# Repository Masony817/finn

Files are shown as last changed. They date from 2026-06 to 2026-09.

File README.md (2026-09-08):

# FINN

**FINN** is a self-balancing, two-wheeled humanoid style robot. The current state is an open hardware/software
platform for balance control, system identification, and sim-to-real work. This
repo holds everything for the robot: firmware, a system-ID pipeline that
turns bench measurements into a physically-grounded MuJoCo model, and a MuJoCo
sim with a first LQR balance controller.

Status: early and under active solo development. Interfaces move fast and the
controllers are sim-validated, not yet hardware-tuned (see
[Status & limitations](#status--limitations)). If you're building a similar
two-wheeler or reusing the control/sysid tooling, it should be a useful
starting point - hopefully. Issues and questions are more than welcome.

Licensed under [Apache 2.0](LICENSE).

## Repository layout - under development and active changes

```
firmware/finn-mcu/   Teensy 4.1 firmware (PlatformIO) + MJBots Moteus motor control,
                     including system-ID, safety-gated LQR, and capture tools
sim/
  model/finn/        Hand-authored MuJoCo model, meshes (STL), and scene
  config/            Canonical measurements + postprocess config (source of truth)
  generated/         Generated seed models (only the reference bundle is committed)
src/finn/            Shared control, simulation, model, reporting, telemetry
tools/               Host-side CLIs: build the seed model, run the LQR sim,
                     postprocess sysid, environment check
tests/               pytest suite for the host tools
config/              Frame/sign contracts, Scopik profiles, and local motor config
```

## Quick start (host / sim)

Requires Python 3.11 and [uv](https://docs.astral.sh/uv/). Nothing else is
needed for the sim — MuJoCo and SciPy install as self-contained wheels.

```bash
uv sync --locked --extra dev            # create .venv from the locked deps
uv run python tools/check_env.py        # verify the toolchain imports
uv run python tools/run_lqr_sim.py      # run the LQR balance sim
```

To watch the closed-loop controller balance Finn in real time on macOS, run
the same simulation through MuJoCo's `mjpython` launcher. The isolated
Homebrew-Python environment is intentional: `mjpython` requires a framework
Python, while uv's standalone Python does not expose the shared library it
needs.

```bash
uv run --isolated --python /opt/homebrew/bin/python3 \
  mjpython tools/run_lqr_sim.py --viewer --duration-s 30
```

On Linux, use `uv run python tools/run_lqr_sim.py --viewer --duration-s 30`.
Closing the viewer stops the rollout and still writes the partial validation
bundle to `logs/lqr_sim/<ts>/`.

Motor calibration utilities are optional because their Qt GUI dependencies are
large. Install them only on machines that talk to the hardware:

```bash
uv sync --extra dev --extra hardware
```

`run_lqr_sim.py` loads the committed seed model at
`sim/generated/seeded/latest/finn.seeded.sim.xml`, linearizes the balance
dynamics, designs a discrete LQR gain, and runs a closed-loop MuJoCo rollout.
It writes a timeseries CSV, a JSON report, and a plot to `logs/lqr_sim/<ts>/`.
By default it derives the stationary balance trim from the model's axle-to-COM
offset and uses a slower position outer loop to prevent accumulated wheel creep.
Override the trim with `--target-pitch-rad`, or disable position hold with
`--position-hold-kp-s 0`, when testing the inner balance loop in isolation.
See `--help` for tuning knobs (Q/R weights, initial pitch, duration).

## Sim-to-real gap profiling

[`packages/scopik`](packages/scopik) replays a recorded Finn run through the
seeded MuJoCo model, compares signals phase by phase, and writes deterministic
bias/RMS/gain/lag diagnostics alongside a Rerun dashboard:

```bash
uv run scopik gap --profile config/viz/finn.yaml \
  --run logs/finn-mcu/sysid/batch_2_pass/<timestamp>
```

Use the repo's `finn-gap-review` agent skill after a run when you want a
physics-grounded brief that connects those measurements to the next model
parameter or validation check.

## Real-robot LQR bring-up

The repo now has a deliberately gated Teensy controller and capture path for
the first unsupported-floor balance trials. Start with the motor-disabled frame
and sign check; the firmware will not arm until those physical observations are
recorded in `config/finn_conventions.yaml` and a passing sim run regenerates the
controller header.

See [Real-robot LQR bring-up](docs/real_lqr_bringup.md) for the exact commands,
two-person no-stand procedure, safety limits, and Scopik feedback loop.

## From robot to model: the system-ID pipeline

The MuJoCo model is not guessed — its wheel friction, damping, torque limits,
and inertias come from measurements. The flow is:

1. **Bench + on-robot sysid.** Firmware sketches under
   `firmware/finn-mcu/sysid/` excite the wheels/IMU; capture tools log the
   telemetry.
2. **Postprocess** each batch into identified parameters
   (`tools/postprocess_mujoco.py`, `firmware/finn-mcu/tools/postprocess_*`).
3. **Build the seed model** from the latest clean runs:
   ```bash
   uv run python tools/build_seeded_mujoco_model.py --auto-select-latest 3
   ```
   This aggregates the runs, writes `seeded_measurements.yaml`, and emits the
   MuJoCo XML the sim consumes.

**Raw sysid telemetry is intentionally not committed** — it's large and
robot-specific (see `.gitignore`). The committed
`sim/generated/seeded/latest/` bundle is a working reference model plus its
provenance (`selected_runs.json`, `aggregation_report.md`). If you're building
your own robot, capture your own sysid batches and regenerate the model against
them; if you just want to run the sim, the committed bundle is enough.

## Firmware

The Teensy 4.1 firmware lives in `firmware/finn-mcu/` and builds with
PlatformIO (`pio run`). It talks to moteus motor controllers over CAN-FD. CI
compiles every `[env:*]` in `platformio.ini` and runs cppcheck, so the MCU code
is build-verified on every push.

## Status & limitations

- The LQR gain and trim are **sim validated, not hardware tuned**. The real
  controller starts behind physical sign checks, a host heartbeat, a three-second
  trial limit, and conservative fault limits. The seeded `±1.0 N·m` torque
  envelope recovers about 11 degrees of lean in sim and caps chassis acceleration
  near 3 m/s²; hub-motor capability is much higher, but the first trials
  intentionally do not use it.
- Contact parameters (friction, solref, solimp) are provisional defaults, not
  identified. World-pose / slip accuracy and closed-loop sim-to-real transfer
  are explicitly **not** validated yet.

## Development

```bash
uv run ruff check .          # lint
uv run ruff format .         # format
uv run pytest -q             # host tests; requires a C++ compiler
```

CI runs lint, format-check, tests, and the firmware build on every push to
`main`/`dev` and on PRs.

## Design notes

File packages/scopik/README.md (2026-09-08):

# scopik

**A sim-to-real gap profiler built on [Rerun](https://rerun.io).**

Every robotics project with a simulator eventually asks the same three questions:
*how wrong is my model, where in the run does it diverge, and is it getting better as I
tune it?* Answering them usually means a pile of private matplotlib scripts. scopik is
that pile, done once, properly: bring a MuJoCo model, a robot log, and a ~40-line YAML
profile - get a scrubbable dashboard and a tracked gap history.

```sh
scopik gap --profile config/viz/finn.yaml --run logs/finn-mcu/sysid/batch_2_pass/<ts>
```

```
sim-to-real gap  (5 signals, model: .../finn.seeded.sim.xml)
  signal           unit         rmse        mae  max |err|       n
  ----------------------------------------------------------------
  left_vel         rev/s      0.4387     0.1365      2.979   34075
  right_vel        rev/s      0.4114     0.1241      2.831   34075
  pitch_rate       rad/s     0.01553   0.004634     0.2011   34075
  yaw_rate         rad/s     0.09119    0.03268     0.8195   34075
  forward_accel    m/s²       0.1637    0.07488      1.846   34075
```

## What it does

`scopik gap` loads a recorded run, replays its recorded actuator commands **open-loop**
through the MuJoCo model (each command held for the real inter-sample interval), samples
the model's sensors on the real run's own timestamps, and logs everything to Rerun:

- **Overlay charts** - real and sim in the same plot per compared signal.
- **Residual + rolling RMSE** - model error *localized in time*. A residual spike at
  breakaway points at stiction; error during a PRBS segment points at inertia or
  damping; drift during coastdown points at friction.
- **Events and phases** - lifecycle events and phase-column changes as timeline
  annotations, so a 10-minute sysid run is navigable by segment.
- **Summary** - per-signal RMSE / MAE / max-error table, in the viewer and as
  `scopik_gap.json` next to the run.
- **Deterministic diagnosis** - per phase and signal, compute bias, RMS, gain,
  correlation, and lag. Unsupported gain/lag estimates are written as `null`
  instead of being inferred from quiet sensor noise; findings aggregate the
  strongest patterns without requiring an LLM.
- **Gap history** - each run appends one JSON line (timestamp, model hash, per-signal
  metrics) to `<profile>_gap_history.jsonl`. Tune the model, rerun, watch the numbers
  move. This is the regression-tracking habit that makes the gap actually close.

## Reading the dashboard

The viewer opens with three kinds of tabs:

| Tab | Question it answers |
|---|---|
| **Overview** | How wrong is everything at a glance? All real-vs-sim overlays, plus the summary table and event log. |
| **One tab per signal** | Where does this signal diverge? Big overlay on top, residual + rolling RMSE below. Scrub to the spikes. |
| **Telemetry** | What was the robot actually doing? Raw signal groups (attitude, wheels, commands, health, ...). |

The timeline panel at the bottom scrubs every panel in sync. Double-click a plot to
expand it; drag on the timeline to zoom a segment.

## Physical honesty

Two problems bite every naive sim-vs-real comparison, and scopik has explicit,
opt-in answers for both:

**Gravity in accelerometers.** A MuJoCo accelerometer reports *specific force*
(gravity included) in the sensor's site frame; real IMUs typically report
gravity-removed linear acceleration. `gravity_compensated: true` on a replay sample
subtracts the gravity-reaction term using the site's live orientation each frame -
correct at any attitude, not just upright. On finn this took the forward-acceleration
"gap" from a meaningless 9.7 m/s² (≈ g) to a real 0.16 m/s².

**Externally supported runs.** If the real robot was on a gantry or stand during the
recording, the bare model has no such support - an unbalanced model simply falls over
during open-loop replay, and every comparison is polluted by fall dynamics.
`hold_upright: <free_joint>` models an ideally stiff support: roll and pitch are
projected out every physics step; yaw and translation stay free. The summary panel
states when a hold is active.

And the standing caveat: this is an **onboard-signal, open-loop** comparison.
Rate and velocity signals are the honest comparison set; absolute pose is not
validated by replay.

Replay refuses non-finite commands and non-increasing timestamps rather than
inventing inputs. Intervals are rounded to physics steps and gaps above 0.1 s
are capped; the dashboard and JSON report expose clipped intervals and cumulative
time error. Do not interpret lag as physical latency when these adjustments
are significant.

## The profile

One YAML file adapts scopik to a robot. Paths are relative to the profile file.

```yaml
name: myrobot
model: ../sim/myrobot.xml            # MJCF the replay runs against

source:                              # how to parse the log
  type: prefixed_csv                 # or csv
  file: telemetry.csv
  line_prefix: "data,"               # rows start with this tag
  header_marker: "data,t_us,"        # the first matching line is the CSV header

time: {column: t_us, transform: us_to_s}

signals:                             # column -> chart, with units and transforms
  pitch_rad:      {unit: rad,   group: attitude}
  left_vel_rev_s: {unit: rev/s, group: wheels}
  motor_temp_c:   {unit: "°C",  group: health}

events:                              # optional: timeline annotations
  file: events.log
  prefix: "event,"
  time_index: 1                      # csv field holding the timestamp
  time_transform: us_to_s
  phase_column: phase                # text column whose changes get annotated

replay:                              # optional: enables the sim side + metrics
  actuators: {motor_left: left_cmd_nm}   # model actuator <- command column
  hold_upright: root_freejoint           # optional: ideal external support
  sample:                                # model sensors -> sim signals
    left_vel_rev_s: {sensor: wheel_left_vel, transform: rad_to_rev, unit: rev/s}
    forward_accel:  {sensor: imu_accel, index: 2, gravity_compensated: true}

compare:                             # real signal vs sim signal, by name
  - {name: left_vel, real: left_vel_rev_s, sim: left_vel_rev_s, unit: rev/s}
```

Transforms: `rev_to_rad`, `rad_to_rev`, `deg_to_rad`, `us_to_s`, `ms_to_s`, `negate`,
`{scale: x, offset: y}`, or a list to chain them. The full worked example is finn's
[`config/viz/finn.yaml`](../../config/viz/finn.yaml).

## CLI

```
scopik gap --profile P.yaml --run RUN_DIR      # open the native viewer (default)
    --save out.rrd        write a shareable recording instead
    --serve               host for a connecting viewer
    --no-replay           charts + events only, no sim / metrics
    --model M.xml         override the profile's model
    --window-s 2.0        rolling RMSE window (default 1.0)
    --out gap.json        metrics JSON path (default: RUN_DIR/scopik_gap.json)
    --history H.jsonl     gap history path; --no-history to skip
```

Recordings (`.rrd`) open with `rerun file.rrd` or the web viewer - that's the
share-a-run story: send the file, the recipient scrubs the same dashboard.

For a Finn-specific physical interpretation, invoke `finn-gap-review` in Codex
or `/finn-gap-review` in Claude Code. Both entrypoints use the same checked-in
workflow and treat Scopik's numeric output as evidence rather than asking an LLM
to re-estimate time-series features.

## Scope

Scopik's main job is recorded open-loop sim-to-real comparison. Finn's capture
tools write complete logs first, then invoke `scopik gap` after the motors are
stopped. Generic plugins and 3D reconstruction stay out until a real robot
workflow requires them.

Live streaming was in that same holding pattern until teleop needed it. Driving a
balancing robot by hand is a workflow a post-hoc gap report cannot serve, so
`scopik.live` exists now:

```python
from scopik.live import LiveSession

session = LiveSession.from_columns({"attitude": ("pitch_rad", "yaw_rate_rad_s")})
session.spawn()                      # or .save(path) for CI
session.log_row(time_s, row)         # once per control tick
session.close()
```

It is deliberately much smaller than the gap pipeline: no profile, no model, no
comparison, just named scalars on a shared timeline. A missing column is skipped
rather than raised, because a live sink must never be able to interrupt the
control loop feeding it. `tools/drive_lqr_sim.py` is the reference caller.

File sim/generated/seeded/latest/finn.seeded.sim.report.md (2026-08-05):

# Finn MuJoCo Postprocess Report

- status: `ok`
- strict: `False`

## Inputs
- robot: `sim/model/finn/finn_robot.xml`
- scene: `sim/model/finn/scene.xml`
- config: `sim/config/mujoco_postprocess.yaml`
- measurements: `sim/generated/seeded/latest/seeded_measurements.yaml`
- robot_sha256: `5f6efd330880e4f90dd55f0cedcf454640507549607517dc8a8347013dfbdcfa`
- scene_sha256: `89402558d8c14cec25d80d707238bdd4679cb2d03deae2740c4df397a81d4c57`
- config_sha256: `9bee25e0d508273d1e2ba68235594842f72ff06dbf8bd16e912f3bdfbdfc83ce`
- measurements_sha256: `eed45ac84e7b11befb13326a1758e1865f2ac3917a9644c5193862d73fb6491b`
- onshape_url: `https://cad.onshape.com/documents/ed1c90944582329b3a0c4b53/w/ef6c6e50f2f631eadb017a5a/e/35effa0e1acd53deffeb4bb9`

## Inspection
- root_body: `base_2`
- wheels: `{'left': {'body': 'left_wheel', 'joint': 'left_wheel', 'center_site': 'left_wheel_center'}, 'right': {'body': 'right_wheel', 'joint': 'right_wheel', 'center_site': 'right_wheel_center'}}`
- visual_mesh_geoms: `23`
- collision_mesh_geoms: `23`
- generated_position_actuators: `['left_wheel', 'right_wheel']`

## Missing Measurements
- none

## Measurements Used
- wheels.left.radius_m: `0.081` m (source: `measured`)
- wheels.left.width_m: `0.053` m (source: `measured`)
- wheels.left.torque_limit_nm: `1.0` N*m (source: `reviewed`)
- wheels.left.gear_ratio: `1.0` ratio (source: `measured`)
- wheels.left.command_sign: `-1` sign (source: `moteus`)
- wheels.left.damping: `0.00410667` N*m*s/rad (source: `moteus`)
- wheels.left.armature: `0.0` kg*m^2 (source: `moteus`)
- wheels.left.frictionloss: `0.115429` N*m (source: `moteus`)
- wheels.left.mass_kg: `2.1` kg (source: `measured`)
- wheels.right.radius_m: `0.081` m (source: `measured`)
- wheels.right.width_m: `0.053` m (source: `measured`)
- wheels.right.torque_limit_nm: `1.0` N*m (source: `reviewed`)
- wheels.right.gear_ratio: `1.0` ratio (source: `measured`)
- wheels.right.command_sign: `1` sign (source: `moteus`)
- wheels.right.damping: `0.00441399` N*m*s/rad (source: `moteus`)
- wheels.right.armature: `0.0` kg*m^2 (source: `moteus`)
- wheels.right.frictionloss: `0.126772` N*m (source: `moteus`)
- wheels.right.mass_kg: `2.1` kg (source: `measured`)
- contact.tire.friction: `[1.0, 0.02, 0.002]` slide torsional rolling (source: `estimated`)
- contact.tire.solref: `[0.02, 1.0]` timeconst dampratio (source: `estimated`)
- contact.tire.solimp: `[0.9, 0.95, 0.001, 0.5, 2.0]` dmin dmax width midpoint power (source: `estimated`)

## Changes
- root: `{'renamed_from': 'base_2', 'renamed_to': 'base_link', 'freejoint_added': True, 'freejoint_name': 'root_freejoint', 'initial_clearance_m': 0.003, 'lift_applied_m': 0.044000000000000004, 'wheel_world': {'left': {'center_z_before_lift_m': 0.04, 'bottom_z_before_lift_m': -0.041}, 'right': {'center_z_before_lift_m': 0.04, 'bottom_z_before_lift_m': -0.041}}}`
- removed_collision_geoms: `[{'name': None, 'mesh': 'motor_hub', 'material': 'motor_hub_material', 'region': 'wheel'}, {'name': None, 'mesh': 'motor_tire', 'material': 'motor_tire_material', 'region': 'wheel'}, {'name': None, 'mesh': 'motor_hub', 'material': 'motor_hub_material', 'region': 'wheel'}, {'name': None, 'mesh': 'motor_tire', 'material': 'motor_tire_material', 'region': 'wheel'}]`
- removed_actuators: `[{'tag': 'position', 'name': 'left_wheel', 'joint': 'left_wheel'}, {'tag': 'position', 'name': 'right_wheel', 'joint': 'right_wheel'}]`
- updated_joints: `[{'wheel': 'left', 'joint': 'left_wheel', 'damping': 0.00410667, 'armature': 0.0, 'frictionloss': 0.115429}, {'wheel': 'right', 'joint': 'right_wheel', 'damping': 0.00441399, 'armature': 0.0, 'frictionloss': 0.126772}]`
- updated_inertials: `[{'wheel': 'left', 'body': 'left_wheel', 'mass_kg': 2.1}, {'wheel': 'right', 'body': 'right_wheel', 'mass_kg': 2.1}]`
- added_actuators: `[{'name': 'motor_left_wheel', 'joint': 'left_wheel', 'gear': -1.0, 'ctrlrange': [-1.0, 1.0]}, {'name': 'motor_right_wheel', 'joint': 'right_wheel', 'gear': 1.0, 'ctrlrange': [-1.0, 1.0]}]`
- added_collision_geoms: `[{'name': 'left_tire_collision', 'body': 'left_wheel', 'type': 'cylinder', 'condim': 6, 'radius_m': 0.081, 'half_width_m': 0.0265}, {'name': 'right_tire_collision', 'body': 'right_wheel', 'type': 'cylinder', 'condim': 6, 'radius_m': 0.081, 'half_width_m': 0.0265}]`
- added_sensors: `[{'tag': 'gyro', 'name': 'imu_gyro', 'target': 'imu'}, {'tag': 'accelerometer', 'name': 'imu_accelerometer', 'target': 'imu'}, {'tag': 'framequat', 'name': 'imu_quat', 'target': None}, {'tag': 'framepos', 'name': 'base_pos', 'target': None}, {'tag': 'framequat', 'name': 'base_quat', 'target': None}, {'tag': 'jointpos', 'name': 'wheel_left_pos', 'target': 'left_wheel'}, {'tag': 'jointvel', 'name': 'wheel_left_vel', 'target': 'left_wheel'}, {'tag': 'jointpos', 'name': 'wheel_right_pos', 'target': 'right_wheel'}, {'tag': 'jointvel', 'name': 'wheel_right_vel', 'target': 'right_wheel'}]`
- scene: `{'compiler_meshdir': '../../../model/finn/assets', 'visual_merged': True, 'assets_merged': 3, 'worldbody_children_merged': 2}`

## Validation
- sensor_model: `ideal; no noise/filter settings were applied`
- mujoco: `{'status': 'ok', 'nbody': 4, 'njnt': 3, 'nu': 2, 'nsensor': 9, 'zero_control_steps': 25}`

## Errors
- none

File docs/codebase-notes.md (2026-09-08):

# Codebase notes

Cross-cutting facts that are easy to get wrong and belong to no single file.
Conventions and rules live in `CLAUDE.md`; this is the reference behind them.

## Signal frames

`config/finn_conventions.yaml` is the contract. Robot +x is forward, +y left,
+z up. The BNO085 is mounted so its own axes do not line up with the robot's:

| Robot quantity | IMU sensor axis | Sign |
|---|---|---|
| pitch, pitch rate | X | +1 |
| yaw, yaw rate | Y | +1 |
| forward acceleration | Z | -1, sensor +Z points aft |

Both physical wheel encoders read positive for robot-forward motion. The
generated MuJoCo model mirrors its left joint, so the simulated left wheel reads
negative for the same motion and Scopik negates only that sensor. These are
separate from the model's own joint-to-world mapping, which is not the same
pairing; `config/finn_conventions.yaml` explains why and holds both.

## MuJoCo

**Accelerometers report specific force**, gravity included, in the sensor site
frame. The firmware publishes BNO085 linear acceleration with gravity already
removed. Comparing them raw shows a ~9.7 m/s^2 gap that is just g, which is why
replay samples take `gravity_compensated: true` and subtract the gravity-reaction
term from the site's live orientation each frame.

**`framequat` objtype matters.** `objtype="body"` reports the body's inertial
(principal-axis) frame, not its body frame; `objtype="xbody"` reports the body
frame. They differ whenever the inertia tensor is not axis-aligned, and the
difference is silent. The seeded model reads attitude off `objtype="site"`
sensors, which sidesteps this.

**A bare model falls over.** Finn is an inverted pendulum, so open-loop replay of
a gantry-supported recording tips within about two seconds and pollutes every
signal with fall dynamics. `hold_upright: <freejoint>` projects roll and pitch
out each step to model an ideally stiff support, leaving yaw and translation
free. Use it only for runs that really were externally supported.

## Control layering

The balance loop is always on. Everything that steers Finn sits above it and can
only move a bounded reference, never a torque. Keyboard teleop is the first tenant of
that layer; an HRI or navigation policy is meant to be the next one, and the
boundary accepts bounded references. Current callbacks run synchronously and
must return immediately; a slow producer must publish through a separate worker
before it can use this interface.

```
L3  command sources   keyboard teleop | scripted profile | (later) a policy
      |               returns DriveCommand(forward_vel_m_s, yaw_rate_rad_s)
L2  command arbiter   holds, clamps, slew-limits, ramps stale commands to zero
      |               output is a reference, never a torque
L1  balance + yaw     runs every tick whether or not a command ever arrives
      |               balance torque allocated first, yaw gets the headroom
L0  safety / arming   stops everything above it; nothing above relaxes it
```

Five invariants, each with a test named for it in
`tests/test_run_lqr_sim_smoke.py` and `tests/test_drive_lqr_sim.py`:

1. **L1 never depends on L3 existing.** With no command source, the rollout is
   identical to the station-keeper, which is what lets the generated firmware
   header keep being exported from the plain balance path.
2. **L3 cannot reach torque.** A command source takes `time_s` and returns a
   `DriveCommand`. It gets no `MjData`, no handles, no gains. This is why the
   `on_tick` hook `make_balance_demo.py` uses for shoves is *not* the teleop seam:
   `on_tick` hands out `MjData`, and it fires after the torque is already computed.
3. **L2 fails closed and fails soft.** A source that raises, returns non-finite or
   wrong-typed values, or goes silent is held briefly and then *ramped* to zero.
   Ramped, not stepped: a step is itself a disturbance the balance loop must reject.
4. **L2 holds intermittent commands.** L1 runs at 100 Hz and continues ramping
   toward the last requested target between samples, until timeout. Callbacks
   must return immediately; this interface does not isolate blocking producers.
5. **Balance has torque priority.** `allocate_wheel_torques` clamps the balance
   torque first and gives yaw only the leftover headroom, so a saturated balance
   loop steers not at all rather than losing authority to a turn request.

Key release, a dropped link, and a stopped policy are the same event to L2, which
is why the teleop release path is also the policy-failure path.

## Viewer keys

Use arrow keys to drive and space to stop. MuJoCo binds every letter to a
rendering shortcut, so Finn does not bind WASD or maintain viewer-flag workarounds.

## Hold to drive

`key_callback` is `Callable[[int], None]`: a keycode and nothing else. No release
events, and no way to separate a press from an auto-repeat. Everything a callback
can manage on its own is therefore a latch - stamp each press, treat the key as
held while the stamp is fresh - and that is a poor joystick. It needs auto-repeat
to arrive, it stutters when the repeat delay outlasts the window, and it keeps
driving for a whole window after release. A 30 s hand-driven session produced no
command plateau longer than a single tick.

GLFW knows the true state of every key and MuJoCo already depends on it. The one
missing piece is the window handle, which the viewer does not expose. It can be
taken instead: `key_callback` runs on the thread holding the GL context, so the
first keypress captures it with `glfw.get_current_context()`. After that
`held()` reads real state, and holding a key holds the command.

GLFW calls fall back to the latch on Python exceptions; this is a best-effort
simulator UI adapter, not a hardware command transport or a thread-safety
guarantee. `report.json` records `key_state_polling`.

## Judging a driven rollout

`run_lqr_sim.py`'s pass gate assumes station keeping: hold a spot, end upright at
trim. Every one of those criteria is wrong for a rollout that was told to drive,
and each was found by a driven run failing for a reason that was actually correct
behaviour.

- **Position hold** becomes command tracking, since a driving robot is not trying
  to hold a spot.
- **Ending upright** allows the lean a still-accelerating command requires.
  Holding forward acceleration `a` costs a steady lean of `atan(a/g)`, so a run
  that stops mid-ramp is upright exactly when it sits inside that plus the
  settling slack.
- **Tracking error** is scored only on samples whose command has been steady for
  `COMMAND_SETTLE_S`, so the slew ramps are not counted as failures, and only on
  *nonzero* commands, and as a p95 rather than a max because a hard spin makes the
  tires stick and slip.

That last filter matters more than it looks. Grading zero commands means grading a
standing robot against a stop, which it always wins. A 30 s hand-driven session
scored 1186 such samples, reported `yaw_tracking_p95 = 0.0009` while yaw had been
commanded to plus and minus 1.0 rad/s, and passed - because a human never holds a
key still for 1.5 s, so not one moving sample was ever graded. The metrics now
carry `*_tracking_assessed` and `*_tracking_samples`, and an unassessed gate says
so instead of printing a reassuring number.

Interactive sessions routinely come back unassessed. That is the honest answer:
the checks that need no steady command - did not fall, ended upright, stayed
inside the torque envelope, did not saturate - still apply.

## Steering signs

Two traps, both recorded in `config/finn_conventions.yaml`.

**The generated model's wheel names are backwards.** `motor_left_wheel` drives the
wheel at world y = -0.009 and `motor_right_wheel` the one at y = +0.508, while
robot +y is left. The names come from the CAD export. Balance never noticed,
because both wheels get the same torque; steering is the first thing that needs
them to differ, and a sign read off the names turns left into right.
`yaw.sim_left_actuator_yaw_sign` carries it, and
`test_positive_yaw_torque_turns_the_model_left` holds it to measured behaviour.

**There is no usable track width.** Three values disagree: 0.517 m from CAD body
origins, 0.583 m between compiled tire contact patches, and 0.351 m from the
gantry-biased Batch 2 yaw response. So no track width appears in the controller at
all. `linearize_yaw_dynamics` identifies the scalar yaw plant by finite difference
on the model, the same way the balance A/B are identified, which also means the
sign of the identified input gain carries the steering direction rather than a
constant someone derived.

Yaw rate itself comes straight off `imu_gyro[1]`, never from differencing the
wheels, for the same reason.

## Telemetry format

The MCU writes line-prefixed CSV over serial: `schema,` and `data,` rows are
telemetry, and `event,`, `status,`, and `check,` lines are the event log.
`serial_log_capture.py` splits them into `telemetry.csv` and `events.log` in the
run directory.

Scopik profiles address telemetry columns by name, and the batch postprocessors
address them positionally by schema tag. Renaming or reordering a column is a
contract change across firmware, profile, and postprocessor; change all three in
one commit, and bump the schema tag when the layout moves.

The LQR controller is on `lqr_v2`, which added command-layer, timing, and
microsecond IMU-age columns to `lqr_v1`. `postprocess_lqr_balance.py` reads it by
name off the header row and refuses a run whose schema tag it does not know,
rather than silently misreading columns. Two tests hold the format together:
`test_firmware_header_and_row_have_the_same_column_count` counts printf
conversions against the header string in `main.cpp`, and
`test_scopik_lqr_profile_only_reads_columns_the_firmware_emits` stops the profile
drifting away from the firmware.

## Arming preflight

`ARM FINN` does not arm. It enters a two second motors-stopped state that samples
the IMU and the CAN bus at the control rate, then evaluates a battery of named
checks and arms only if every one passes. `PREFLIGHT` runs the same battery and
returns to idle, so a failure can be chased without touching the arm path.

Sampling over a window rather than probing once is the whole point. The failures
that end a balance trial are intermittent: a marginal I2C pull-up that drops one
report in twenty, a CAN termination fault that costs replies under load, a pack
that only sags when queried at 100 Hz. A single-shot check sees none of them.

The checks are emitted as `check,<t_us>,<name>,<pass|fail|skip>,<measured>,<limit>,<detail>`
so the operator, the terminal, and the postprocessor all read the same record.
`skip` exists for a real case rather than as a placeholder: `bus_voltage_floor`
has no value to compare against, because no bus voltage is recorded anywhere in
this repo, so it reports the measurement and declines to gate until
`kMinBusVoltageV` is set.

The host runs a parallel check the firmware cannot: `LiveIntegrityMonitor` in
`capture-lqr-balance.py` watches the schema tag, per-row column count, and
non-finite values as they land, because the MCU has no way to know what actually
arrived at the other end of the USB cable.

## Host tooling

Shared Finn Python lives in `src/finn/` and is installed by `uv sync`.
`control.py` has no simulator dependency; `simulation.py` owns MuJoCo dynamics;
`lqr.py` owns validation/export; `reporting.py` assesses traces and writes plots.
`model.py` applies measured physics, and `telemetry.py` shares sysid parsing.
The existing CLI paths remain wrappers. Remaining standalone tools are loaded
by file in tests only; production callers use ordinary package imports.

The builder's optional Batch 2 replay uses Scopik and `config/viz/finn.yaml`.
Replay rejects non-finite commands and non-increasing timestamps; its report
records integration-time adjustments caused by timestep rounding and capped gaps.

Rerun is pinned to 0.34.x and every call into its API lives in
`packages/scopik/src/scopik/rrlog/`. Keep it there: the SDK is pre-1.0 and moves,
and containment is what makes a version bump a one-directory change.

## Model provenance

`sim/model/finn/finn_robot.xml` is an onshape-to-robot export, kept as a source
and re-exported when the CAD changes. Its `<!-- Part ... -->` labels are
generator output. Do not hand-tune inertias or geometry here; correct the CAD or
the measurement, then rebuild through the seeded-model pipeline.

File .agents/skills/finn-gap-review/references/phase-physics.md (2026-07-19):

# Finn phase-to-physics map

Use this map after validating Scopik's numeric evidence. Parameter suspects are ordered, not exclusive.

## Evidence semantics

- Bias: mean `sim - real`. Check sign consistency across positive/negative commands before calling it a constant offset.
- RMS: magnitude only. Concentration by phase is more useful than whole-run rank.
- Gain: scaling mismatch after de-meaning. Negative gain usually means sign/frame error or poor excitation, not a negative physical constant.
- Lag: timing clue, not an actuator-delay measurement unless an excitation phase has enough bandwidth and repeatability.
- Left/right symmetry: common error points toward shared motor/contact/model terms; opposite error points toward sign, asymmetry, or yaw geometry.

## Phase families

| Phase family | What it excites | First suspects | Do not infer |
|---|---|---|---|
| `initial_stationary_noise`, `final_stationary_noise`, `idle` | zero-command hold and sensor floor | wheel `frictionloss`, contact stiction, command bias, sensor zero | inertia or delay |
| `creep_*` | loaded breakaway at low torque | loaded friction/stiction, torque calibration, left/right asymmetry | viscous damping from a single plateau |
| `straight_*` | common-mode loaded drive | torque scale, wheel radius, reflected inertia/armature, rolling resistance | track width from common motion |
| `yaw_*` | differential drive and yaw response | effective track width, yaw inertia, command signs, asymmetric friction | forward trajectory fidelity |
| `coast_spinup_*` | driven approach to coast initial state | torque scale, inertia, damping | pure coast loss until command is zero |
| `coastdown_*` | unpowered decay | Coulomb/rolling loss, viscous damping, wheel/system inertia | actuator delay |
| `*_settle` | return to rest | stiction floor, damping, residual command or support interaction | trustworthy gain/lag when real activity is small |
| `prbs_straight` | broadband common-mode wheel dynamics | actuator delay, torque scale, armature/inertia, damping | yaw geometry |
| `prbs_differential` | broadband differential/yaw dynamics | actuator delay, track width, yaw inertia, asymmetric friction | absolute world pose |

## Signal-specific checks

### Wheel velocity

- Real near zero while sim moves during stationary or settle phases strongly supports insufficient simulated loss under load.
- Similar left/right gain error supports a shared torque-scale, radius, inertia, or damping mismatch.
- Opposite signs or strong left/right disagreement requires checking command and sensor conventions before tuning physics.
- Coastdown error that changes with speed supports damping; a roughly speed-independent stopping threshold supports Coulomb/rolling loss.

### Pitch and yaw rate

- With `hold_upright`, pitch-rate agreement is only a supported onboard-rate check.
- Yaw-rate mismatch concentrated in differential phases supports track-width/yaw-inertia review.
- Straight-phase yaw rate points first to left/right asymmetry or support interaction.

### Forward acceleration

- Check IMU axis/sign and gravity compensation before physical tuning.
- Compare positive and negative straight phases. A sign-dependent discrepancy suggests frames, command convention, or asymmetric contact; a symmetric scale error suggests mass/torque/radius.
- Large coastdown acceleration error may reflect contact loss modeling, but does not by itself identify a unique friction coefficient.

## Parameter source map

- Physical measurements and CAD-reviewed values: `sim/config/finn_measurements.yaml`.
- Batch-derived actuator and loaded-loss seeds: each selected run's `derived.yaml`, aggregated by `tools/build_seeded_mujoco_model.py`.
- MuJoCo translation rules and contact defaults: `sim/config/mujoco_postprocess.yaml` and `tools/postprocess_mujoco.py`.
- Generated evidence: `sim/generated/seeded/latest/seeded_measurements.yaml`, `aggregation.json`, and `validation.json`.
- Generated MJCF: inspect it, but do not edit it as the source of truth.

When testing a hypothesis, prefer a standalone candidate measurement YAML or explicit build input over mutating a generated bundle in place. Reprocess the same old runs after a pipeline change before comparing new captures.

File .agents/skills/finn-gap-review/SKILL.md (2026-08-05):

---
name: finn-gap-review
description: Review Finn Scopik sim-to-real gap artifacts and turn deterministic per-phase bias, RMS, gain, correlation, and lag evidence into a concise physics-grounded diagnosis and next model-validation step. Use when asked to interpret scopik_gap.json, compare Finn gap runs or history, explain which MuJoCo parameter is suspect, or prepare a sim-real brief after Batch 2 or LQR telemetry.
---

# Finn Gap Review

Review the computed evidence; do not ask an LLM to re-estimate time-series features.

## Gather evidence

1. Resolve the requested run. If none is named, list candidate run directories and use the newest run containing `scopik_gap.json`; state the choice.
2. Read, in order:
   - `<run>/scopik_gap.json`
   - `<run>/events.log`
   - `config/viz/finn.yaml`
   - `config/viz/finn_gap_history.jsonl`, when present
   - `sim/generated/seeded/latest/selected_runs.json`
   - `sim/generated/seeded/latest/seeded_measurements.yaml`
   - `sim/generated/seeded/latest/validation.json`
3. Read `references/phase-physics.md` completely before mapping a pattern to a parameter.
4. Inspect telemetry rows around a cited phase only when the JSON evidence is ambiguous. Do not load an entire large CSV into the prompt.

If the gap JSON is missing or older than the telemetry or model, rerun without changing tracked history:

```bash
uv run scopik gap --profile config/viz/finn.yaml --run <run> \
  --out /tmp/finn-scopik-gap.json --save /tmp/finn-scopik-gap.rrd --no-history
```

Append normal history only when the user intends the run to become a recorded baseline.

## Validate evidence

- Confirm the run, model path, model hash when available, profile, and replay scope.
- Treat `bias` as `sim - real`.
- Treat `gain` and `lag_s` as unavailable when null.
- Use gain only with adequate phase activity and `abs(correlation) >= 0.6`.
- Positive lag means sim later than real. Trust lag primarily in PRBS or pulse excitation. Discount settle, stationary, coastdown, monotonic, and near-window-boundary estimates.
- Compare repeated phases, both directions, and both wheels. A one-off phase is weak evidence.
- Separate a deterministic Scopik finding from its physical interpretation. A finding is a screening result, not proof of one parameter.

## Preserve validation boundaries

- Batch 2 replay is open-loop and gantry-supported. It validates onboard sensor and actuator response, not world trajectory, absolute slip, endpoint error, or free-balancing transfer.
- `hold_upright` changes the physics. Do not interpret supported pitch response as free LQR balance behavior.
- Never claim a parameter is identified from a signal that does not excite it independently.
- Do not hand-edit `sim/generated/seeded/latest/finn.seeded.sim.xml`. Change a source measurement, derived sysid output, or an explicit candidate overlay, then rebuild and compare.
- Change one coupled parameter family per iteration unless the effects are independently observable.

## Produce the brief

Lead with a one-sentence verdict, then use exactly these sections:

1. `Good` - evidence that agrees, is repeatable, or clears a concern.
2. `Issues` - each item includes signal, phase family, numeric evidence, interpretation, and confidence (`high`, `medium`, or `low`).
3. `Next change` - one parameter family, its source file or generation path, expected directional effect, rebuild/rerun command, and a falsifiable success criterion.
4. `Boundary` - the strongest conclusion this run cannot support.

Prefer “inspect X next” over “tune X” when evidence is not identifiable. Never invent a numeric parameter adjustment from residual metrics alone.

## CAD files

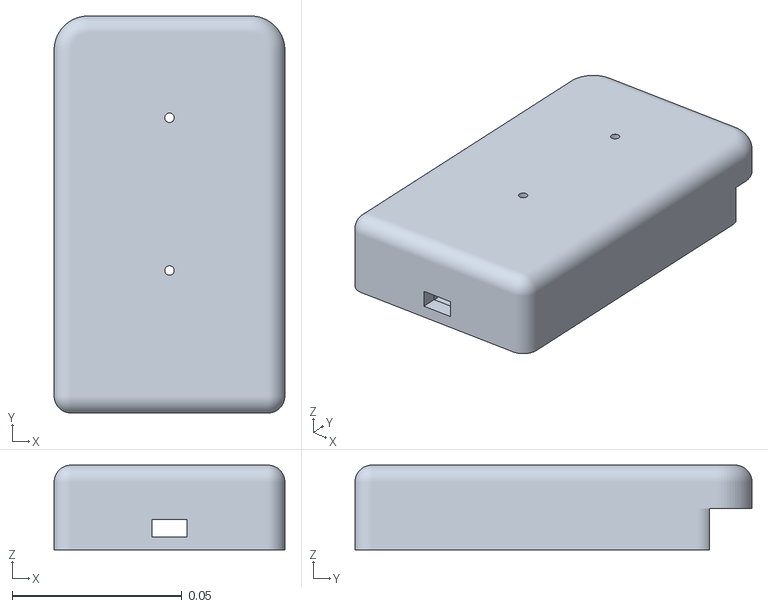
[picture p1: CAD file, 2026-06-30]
sim/model/finn/assets/battery_adapter.stl
0.068 x 0.117 x 0.025

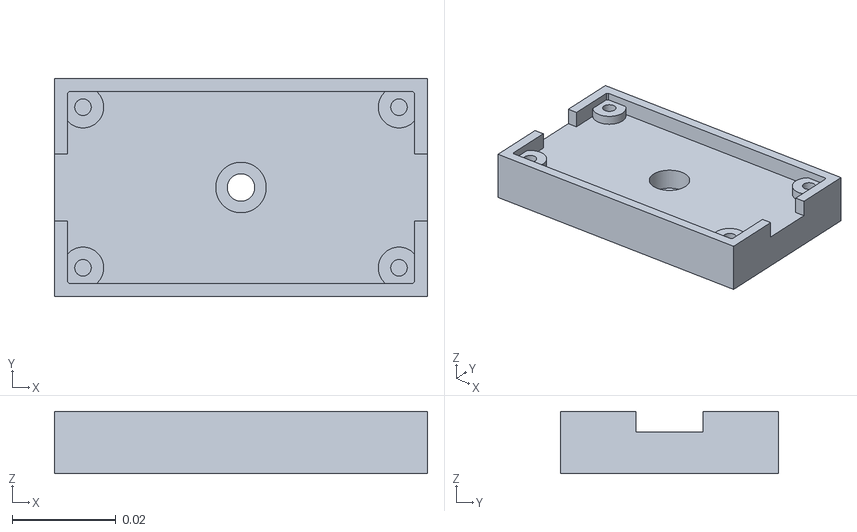
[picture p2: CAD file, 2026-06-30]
sim/model/finn/assets/dcdc_converter_bracket.stl
0.072 x 0.042 x 0.012

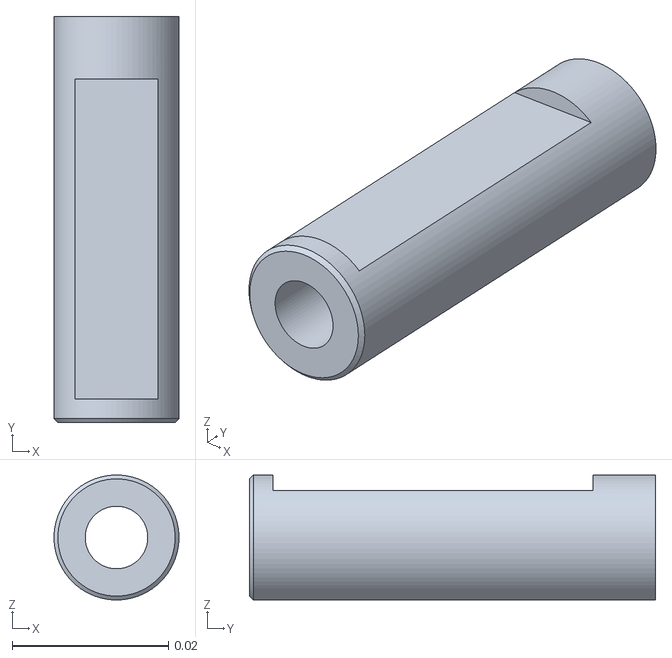
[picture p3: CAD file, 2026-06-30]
sim/model/finn/assets/right_motor_shaft.stl
0.016 x 0.052 x 0.016

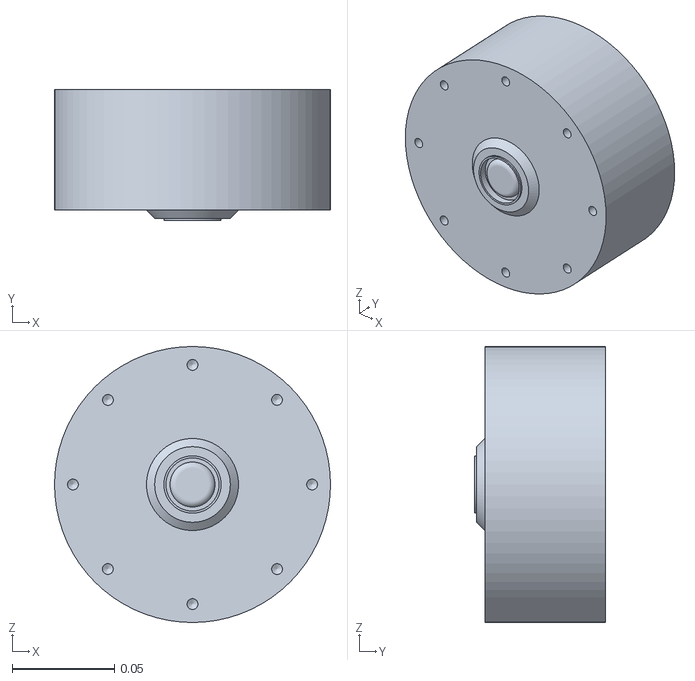
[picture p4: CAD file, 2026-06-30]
sim/model/finn/assets/motor_hub.stl
0.135 x 0.064 x 0.135

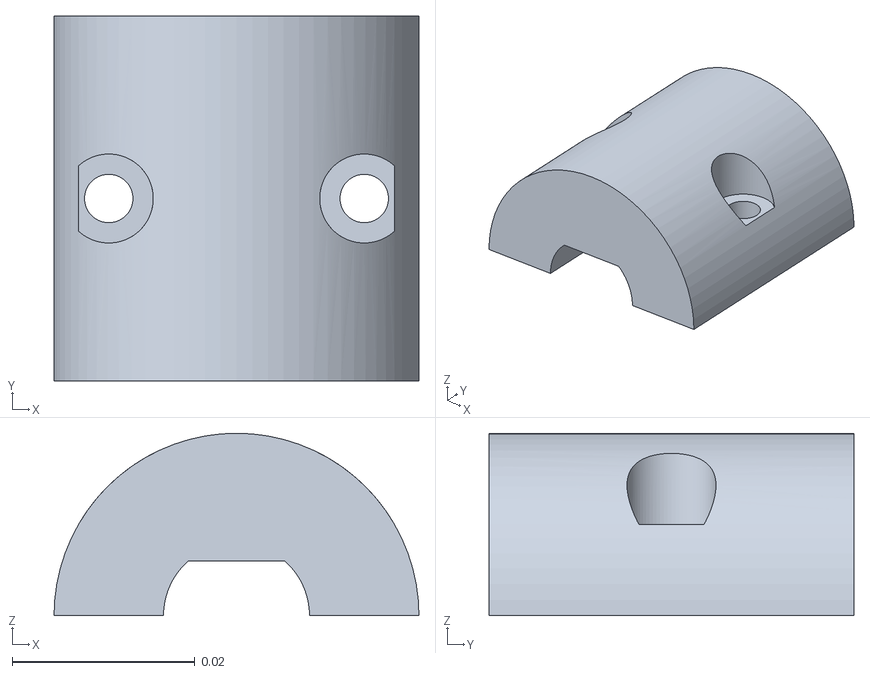
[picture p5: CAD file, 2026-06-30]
sim/model/finn/assets/motor_bk_top.stl
0.04 x 0.04 x 0.02

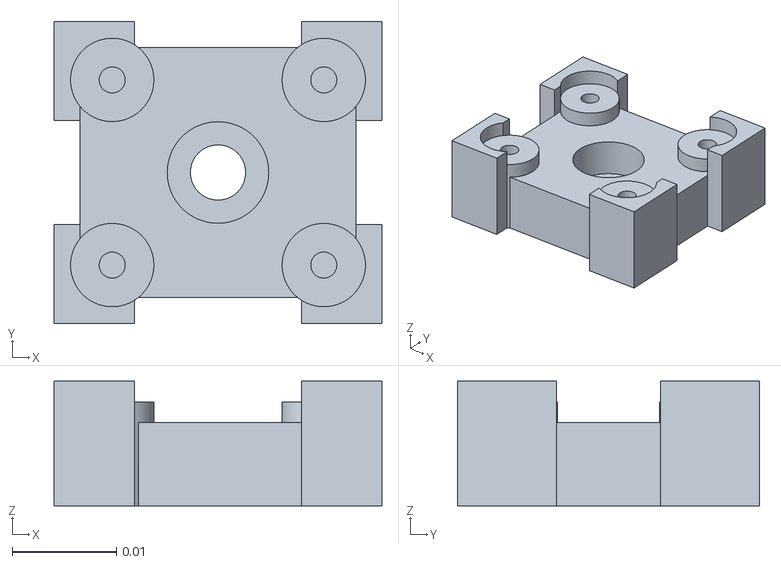
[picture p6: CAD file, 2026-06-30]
sim/model/finn/assets/bno085_bracket.stl
0.0315 x 0.029 x 0.012

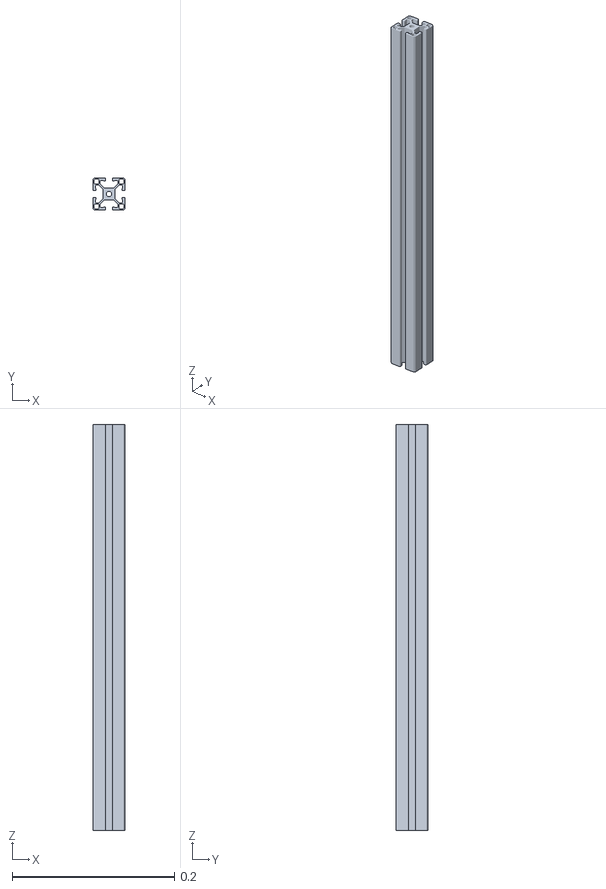
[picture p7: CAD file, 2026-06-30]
sim/model/finn/assets/base_rail.stl
0.04 x 0.04 x 0.5

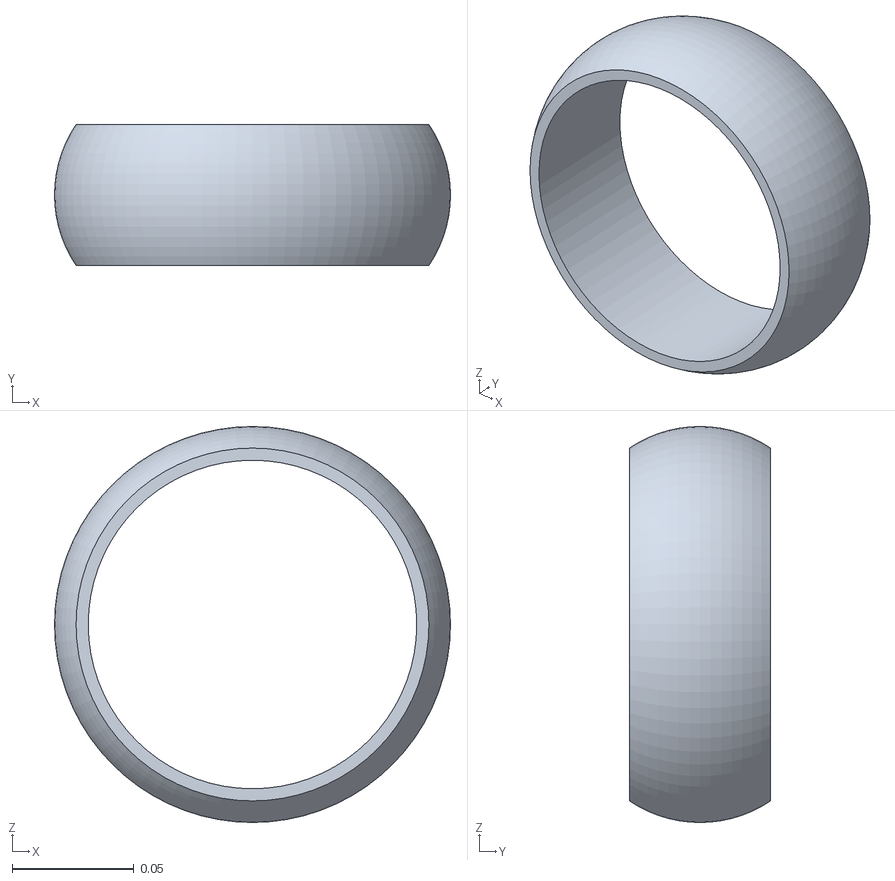
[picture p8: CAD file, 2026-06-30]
sim/model/finn/assets/motor_tire.stl
0.163 x 0.058 x 0.163

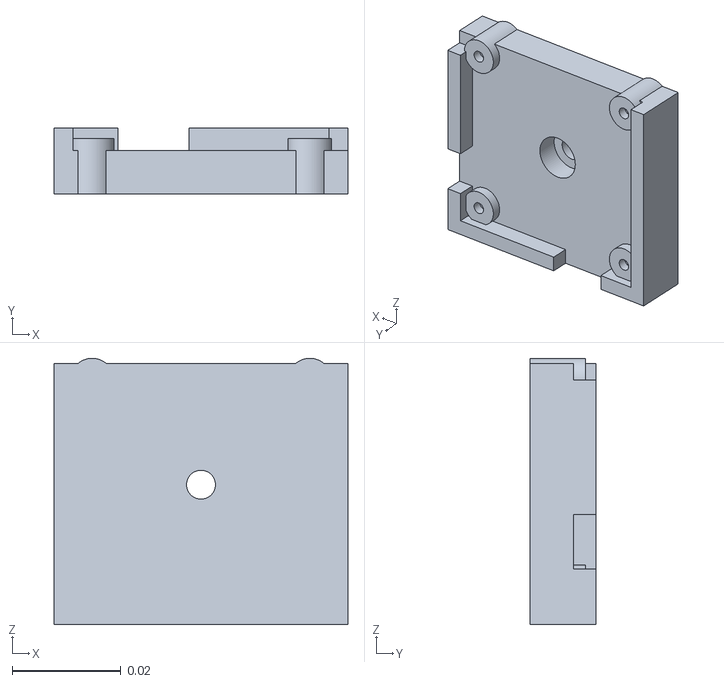
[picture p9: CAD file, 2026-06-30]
sim/model/finn/assets/motues_bracket.stl
0.054 x 0.0122 x 0.0489

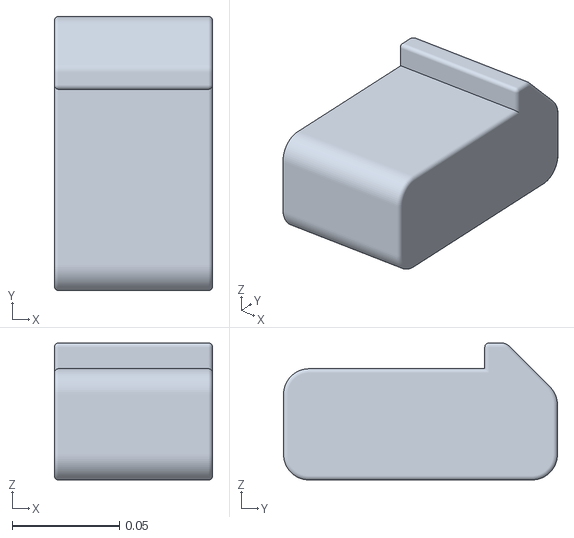
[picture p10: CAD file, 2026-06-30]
sim/model/finn/assets/battery_mass.stl
0.074 x 0.128 x 0.064

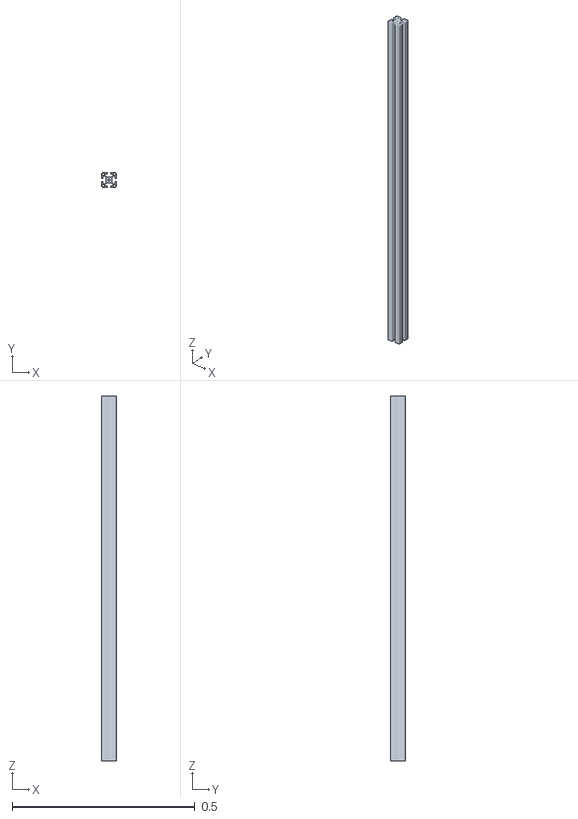
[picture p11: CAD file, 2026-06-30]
sim/model/finn/assets/mast.stl
0.04 x 0.04 x 1.00

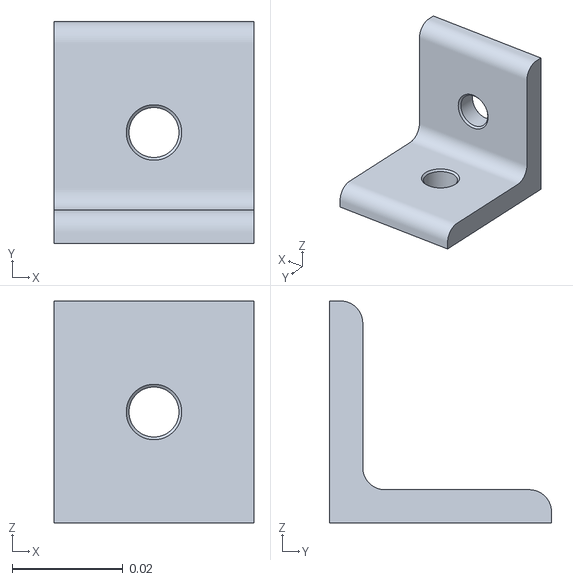
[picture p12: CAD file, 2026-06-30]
sim/model/finn/assets/mast_bracket.stl
0.036 x 0.04 x 0.04

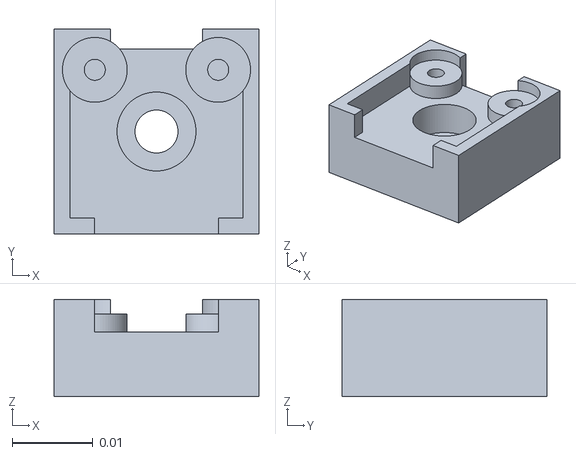
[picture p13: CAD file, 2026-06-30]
sim/model/finn/assets/canpal_bracket.stl
0.0253 x 0.0253 x 0.012

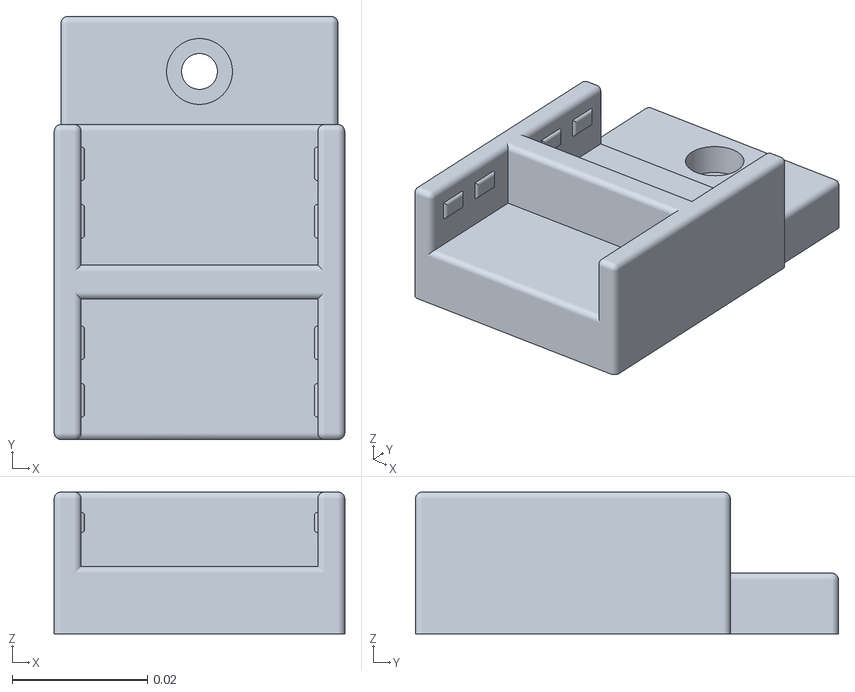
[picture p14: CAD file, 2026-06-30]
sim/model/finn/assets/5b_wago_bracket.stl
0.043 x 0.0626 x 0.021

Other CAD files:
sim/model/finn/assets/teensy_bracket.stl
sim/model/finn/assets/motor_bk_bottom.stl

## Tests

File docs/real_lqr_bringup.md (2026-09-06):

# Real-robot LQR bring-up

This is the supported path from the committed seeded MuJoCo model to a short
free-standing Finn balance trial. The controller has not balanced the physical
robot yet. The interlocks here reduce the cost of a mistake; they do not make a
falling 8.44 kg robot safe.

## What is canonical

- `sim/generated/seeded/latest/finn.seeded.sim.xml` is the model used to design
  and validate the gain.
- `config/finn_conventions.yaml` is the sign and frame contract shared by the
  model, Scopik, and firmware.
- `tools/run_lqr_sim.py` derives the gain and exports
  `firmware/finn-mcu/control/04_lqr_balance/lqr_seeded_config.h` after a passing
  rollout. Do not tune the generated header by hand.
- `firmware/finn-mcu/control/04_lqr_balance/lqr_safety_config.h` contains the
  separately reviewed physical safety limits, including the preflight thresholds
  and the drive gate.
- `config/viz/finn_lqr.yaml` tells Scopik how to replay a recorded LQR command
  trace through the free model. It reads telemetry schema `lqr_v2`.
- `firmware/finn-mcu/tools/postprocess_lqr_balance.py` turns a captured run into
  derived model corrections, the way the Batch 1 and Batch 2 postprocessors do.
- `tools/drive_lqr_sim.py` drives the same validated controller around from the
  keyboard or a scripted profile. Sim only; see Stage 5.

The controller state is `[pitch, pitch_rate, forward_velocity]`. Positive robot
X is forward, positive Y is left, and positive Z is up. Both physical wheel
encoders are expected to be positive for robot-forward motion. The mirrored
MuJoCo left joint is negative for forward motion, which is why Scopik negates
only the simulated left-wheel sensor.

## The trial setup

Finn stands free on the floor with a Dyneema sling attached to the top of the
mast. An operator holds the sling slack and takes up no load. The robot balances
entirely on its own wheels; the sling is a catch, not a support.

That distinction is what keeps the run usable as data. A slack sling applies no
force, so the recorded response is the real free-balance response and the model
comparison means something. **A sling that goes taut becomes an external force
the telemetry cannot see**, and nothing downstream can distinguish it from robot
dynamics. If you catch Finn mid-trial, treat everything after that moment as a
catch recording rather than a balance recording, and say so in the run notes. The
postprocessor's steady-state filter drops most of it, but it cannot detect a
gentle load.

For a first free trial, use two people: one on the sling, one operating the host.
Clear the floor and keep hands, clothing, and the USB cable away from the wheels.
Have an accessible hardware motor-power cutoff. The serial `STOP` command and the
moteus watchdog are useful interlocks, but neither replaces a physical cutoff or
a person on the sling. Do not perform the first release alone.

## Before touching the floor

Run the host checks and a full 30 second sim validation:

```bash
uv sync --extra dev
uv run pytest -q
uv run python tools/run_lqr_sim.py \
  --duration-s 30 \
  --no-plot \
  --firmware-header firmware/finn-mcu/control/04_lqr_balance/lqr_seeded_config.h
```

The last command must report `status=pass`. It records the model hash, gain,
trim pitch, controller timing, and convention flags in the firmware header.

The torque envelope is `1.0 N m` per wheel. It was `0.25 N m` until 2026-08-05,
inherited from whatever hard cap the Batch 1 bench firmware happened to run with
rather than chosen. That value is below what the robot physically needs: with
both wheels capped there, gravity wins past 2.8 degrees of lean, so the arm gate
was allowing release poses the controller could not recover from. At `1.0 N m`
the sim recovers about 11.3 degrees, which covers the 8 degree arm window with
margin, while capping chassis acceleration near 3 m/s^2. The hub motors can
deliver considerably more; raising the envelope again is a later, deliberate
validation step.

## Stage 1: motor-disabled convention check

The committed firmware deliberately refuses to arm because its two hands-on
convention flags start as `false`. Flash and capture the check:

```bash
uv run python firmware/finn-mcu/tools/capture-lqr-balance.py --check-conventions
```

With Finn held and the motors stopped:

1. Type `ZERO UPRIGHT` while the chassis is mechanically upright.
2. Type `CHECK CONVENTIONS`.
3. Tip the top of Finn forward. `pitch_rad` and `pitch_rate_rad_s` must become
   positive.
4. Roll each wheel by hand in the direction that would drive the robot forward.
   Both reported wheel velocities must become positive.
5. Rotate Finn to the left, counter-clockwise seen from above. `yaw_rate_rad_s`
   must become positive. This one gates steering rather than balance, so it can
   be deferred, but it costs nothing to do in the same 15 second window.
6. Let the 15 second check finish. The run is saved under
   `logs/finn-mcu/lqr/lqr_convention_check_pass/`.

If a sign is wrong, update the corresponding sign in
`config/finn_conventions.yaml`, rerun the sim/export command so the motor-disabled
firmware receives the correction, repeat the check, and do not arm. When the
observations are correct, set the matching fields to `true`:

```yaml
imu:
  pitch_direction_bench_verified: true
  yaw_direction_bench_verified: true      # steering only
wheel_odometry:
  encoder_directions_bench_verified: true
```

The first and third gate arming at all. The yaw flag gates only the drive layer,
which is built but held off; see Stage 5.

Then rerun the 30 second sim/export command. That is the only supported way to
open the firmware arm gate.

## Stage 2: arming preflight

`ARM FINN` no longer arms directly. It spends two motors-disabled seconds
sampling every subsystem at the control rate, prints one `check,` line per test,
and arms only if all of them pass. `PREFLIGHT` runs the identical battery but
never arms, so you can iterate on a failure without touching the arm path:

```bash
uv run python firmware/finn-mcu/tools/capture-lqr-balance.py --preflight
```

Hold Finn upright and still for the whole window. What it checks, and why each
one is worth a failed arm rather than a failed trial:

| Group | Checks | What a failure means |
|---|---|---|
| Conventions | `conventions_pitch`, `conventions_wheels` | Stage 1 was not completed, or the header was not regenerated after it. |
| IMU | `imu_present`, `imu_fresh`, `imu_quat_rate_hz`, `imu_gyro_rate_hz`, `imu_accel_rate_hz`, `imu_no_reset`, `imu_quat_norm` | The estimator would run on stale or malformed attitude. Marginal I2C pull-ups show up here and nowhere else. |
| Pose | `imu_stationary`, `pitch_zeroed`, `pitch_near_trim` | The release pose is outside what the torque envelope can recover. |
| CAN and motors | `moteus_left_link_hz`, `moteus_right_link_hz`, `moteus_left_misses`, `moteus_right_misses`, `moteus_left_fault`, `moteus_right_fault`, `moteus_temp_c` | The control loop would lose a wheel mid-trial. |
| Power | `bus_voltage_stable`, `bus_voltage_floor` | The pack sags with the motors already stopped, so it will collapse under balance current. |
| Recording | `telemetry_rate_hz`, `encoders_finite` | The run would produce data too thin to learn anything from. |
| Timing | `control_budget_us` | The CAN round trip does not fit in the 10 ms control period. |
| Host | `host_heartbeat` | The host is not actually holding the deadman. |

`bus_voltage_floor` reports `skip` until you set `kMinBusVoltageV` in
`lqr_safety_config.h` from the pack spec. No bus voltage is recorded anywhere in
this repo, so the check reports the measured value rather than guessing a floor.
Setting it turns the reading into a gate.

The host runs its own check in parallel, because the firmware cannot see the far
end of the USB cable. It verifies the schema tag is one the postprocessor reads,
that every row has the expected column count, and that no non-finite value
arrived. A truncated capture is worth discovering before the release, not after.

## Stage 3: the balance trial

```bash
uv run python firmware/finn-mcu/tools/capture-lqr-balance.py
```

The sling operator holds Finn mechanically upright for `ZERO UPRIGHT`, then holds
it near the generated target trim (`0.0411 rad`, about 2.36 degrees) and still,
for the two second preflight, before `ARM FINN`. Only when both people are ready,
type `RUN LQR` and let the sling go slack.

The trial ends after `kFirstTrialDurationMs`, which is 3 seconds. `TRIAL <ms>`
selects a shorter one; it clamps to `kMaxTrialDurationMs`, which ships equal to
the reviewed 3 seconds so the selectable envelope is exactly the reviewed
envelope. Lengthening a trial means raising `kMaxTrialDurationMs` deliberately,
after short trials show the expected sign, strong real/sim correlation,
acceptable lag, and no unexplained saturation or drift. Every other limit in that
header was sized for a 3 second catch.

Catch Finn on every stop, timeout, or fault; stopped wheels do not keep the
chassis upright. The firmware also stops or refuses to run on stale IMU data,
missing host heartbeat, control-loop deadline miss, moteus fault or missing
reply, excessive pitch, wheel speed, travel, or temperature. A fault stays
latched through `STOP`; fix its cause and type `CLEAR` before rearming.

## Stage 4: read the run back

The capture wrapper runs two postprocess steps automatically.

`postprocess_lqr_balance.py` treats the trial as a sysid run and writes
`postprocess/derived.yaml` and `postprocess/report.md`. It audits recording
integrity first (schema, malformed rows, control-loop jitter, tick duration, IMU
freshness, saturation, preflight check results), then attempts five estimates and
reports an observability verdict for each:

| Estimate | What it needs | Realistic verdict on a quiet trial |
|---|---|---|
| Balance trim / COM fore-aft | A steady mean wheel torque distinguishable from its own noise | Usually identified. This is the most valuable output. |
| Pitch plant (`mgl/I`, `1/I`) | Lean and torque not collinear | Usually `not_excited`. The controller makes torque a function of lean. |
| Actuator torque tracking | Commanded torque range above 0.05 N m | Identified once the controller is working. |
| Loop latency | Correlated command and response | Identified if the trial had any real motion. |
| IMU noise floor | The stationary preflight window | Always identified. Cleanest estimate in the run. |

A closed-loop balance run is a poor identification experiment and the script is
built to say so rather than fit anyway. A parameter whose regressors arrived
collinear is reported `not_excited` with its condition number, not fitted. The
report ends by naming **one** parameter family to change next, because coupled
families cannot be separated in a single iteration.

Change that one thing, regenerate the seeded model and the gain header, and
capture another short trial.

`scopik gap` then replays the recorded command trace through the free seeded
model, producing `scopik_gap.json` and `scopik_gap.rrd`. Treat a failed physical
balance attempt as useful evidence. Scopik's LQR replay compares onboard sensor
and actuator response; it does not prove world trajectory, tire slip, or contact
fidelity, which need an independent pose measurement. Do not tune model
parameters from gain or lag when the absolute correlation for that phase is below
`0.6`.

## Where the earlier batch runs fit

- Batch 1 is the off-ground actuator characterization behind wheel damping,
  friction loss, command signs, and torque limits. Rerun it only after a motor,
  controller configuration, or wheel changes.
- Batch 2 is the gantry-supported ground-contact dataset behind the current
  loaded model checks. It validates onboard sensor/actuator response, not free
  balance or world-path fidelity. Since the gantry is no longer available, keep
  the existing clean runs as provenance rather than pretending an unsupported
  run is the same experiment.
- Short LQR captures are now the next controlled dataset. They should refine
  the transfer story without overwriting the Batch 1/2 evidence.

## Stage 5: driving, and what is still gated

The command layer is now **in** the firmware, not just in the sim. A
`CommandArbiter` holds, clamps, slew limits, and ramps stale intent to zero;
`allocateWheelTorques` gives yaw only the headroom balance leaves behind; and
`DRIVE <forward_m_s> <yaw_rad_s>` parses and validates bounded intent. The
balance loop runs every tick regardless, exactly as before.

None of it moves the robot yet, by three separate gates:

1. **`kDriveEnabled` in `lqr_safety_config.h` is `false`.** Yaw torque is forced
   to exactly zero and the position reference is pinned, so balance is identical
   to the validated station keeper. `DRIVE` is refused with a reason.
2. **`yaw_direction_bench_verified` is `false`.** Even with the gate open, a
   drive command is refused until Stage 1's yaw observation is recorded.
3. **The reviewed safety envelope forbids driving, correctly.**
   `kMaxWheelTravelRev = 2.0` faults at about 1.02 m of travel and
   `kFirstTrialDurationMs = 3000` ends the trial at 3 s, so any real drive
   attempt trips a limit within a second or two. Driving needs its own reviewed
   limit block, set from evidence produced by short balance trials, not from the
   sim.

One physical ceiling sits above all of it: `kMaxAbsPitchRad = 10 degrees` caps
sustained acceleration at `g*tan(10 deg) = 1.73 m/s^2` no matter what the command
layer allows. The sim's 0.5 m/s^2 slew limit is chosen to sit well inside that,
leaning about 2.9 degrees and leaving the rest for disturbance rejection.

Note that the two `SetPosition` calls already cost up to 6 ms of the 10 ms
control budget. Steering changes their values, not their count; the
`control_budget_us` preflight check is what watches that.

`docs/codebase-notes.md` states the layer invariants the firmware preserves.

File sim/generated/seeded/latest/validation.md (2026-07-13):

# Seeded MuJoCo Validation

- status: `ok`
- model_xml: `sim/generated/seeded/latest/finn.seeded.sim.xml`

## Mesh Assets
- status: `ok`

## Checks
- compile: `ok`
- actuators: `2`
- zero_control_settle: qvel_norm=0.05351447453519983
- left_impulse: qvel_norm=0.04576040087843951
- right_impulse: qvel_norm=0.045746626234539824
- equal_wheel_forward: qvel_norm=0.08167473477524184
- opposite_wheel_yaw: qvel_norm=0.08527562447436896

## Scope
- onboard-signal validation only; this does not validate world pose, absolute slip, endpoint error, or closed-loop LQR transfer

## Errors
- none

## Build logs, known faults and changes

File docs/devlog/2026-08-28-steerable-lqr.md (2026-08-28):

# 2026-08-28 - steerable LQR: WASD teleop as the first tenant of a command layer

Raw notes for a later write-up. Everything below was checked against the working
tree on `fix/lqr-grounded-linearization`.

## What shipped

- `tools/drive_lqr_sim.py` (new, 351 lines): WASD teleop plus two scripted
  profiles (`square`, `spin`) over the existing balance controller.
- `tests/test_drive_lqr_sim.py` (new, 264 lines): pure-arithmetic tests for the
  arbiter, the torque allocator, and the keyboard latch. No MuJoCo needed.
- `tools/run_lqr_sim.py`: +529 lines. Command layer, yaw loop, yaw plant
  identification, torque allocation, new pass gate, `on_tick` hook.
- `config/finn_conventions.yaml`: +32 lines. New `yaw:` block.
- `docs/codebase-notes.md`: +64 lines. Control layering and steering signs.
- `docs/real_lqr_bringup.md`: +51 lines. Stage 1 yaw check, new Stage 3.
- `firmware/finn-mcu/control/04_lqr_balance/lqr_seeded_config.h`: +15 lines.
- `CLAUDE.md`: new hard rule 4, old rules 4/5/6 renumbered to 5/6/7.
- Zero firmware source changes. `main.cpp` references none of the new constants
  (`grep -c "kYaw\|kMaxForwardVel\|kDriveAccel" main.cpp` returns 0).

## The actual point: the layer boundary

WASD was the excuse. The goal was a seam an HRI or navigation policy can plug
into later without any of them being able to cost the robot its balance.

```
L3  command sources   WASD teleop | scripted profile | (later) a policy
L2  command arbiter   holds, clamps, slew-limits, ramps stale commands to zero
L1  balance + yaw     runs every tick whether or not a command ever arrives
L0  safety / arming   stops everything above it; nothing above relaxes it
```

- A command source's whole signature is `Callable[[float], DriveCommand]`. It
  sees the clock. It gets no `MjData`, no model handles, no gains. That is the
  entire enforcement mechanism, and it is enforced by the type, not by review.
- `DriveCommand` is two floats: `forward_vel_m_s`, `yaw_rate_rad_s`. Frozen
  dataclass. That is the complete vocabulary L3 may speak.
- Five invariants, each with a test named for it. Written down in
  `docs/codebase-notes.md`, promoted to hard rule 4 in `CLAUDE.md`.
- Nice accident of the design: releasing a key is byte-identical to a dropped
  serial link and to a policy that stopped publishing. All three land in
  `CommandArbiter._held`. So every time someone drives with the keyboard they are
  exercising the policy-failure path.
- The `on_tick` hook that `make_balance_demo.py` uses for shoves is deliberately
  *not* the teleop seam: it hands out `MjData` and fires after the torque is
  already computed. Two hooks, two trust levels.

## Design decision: yaw is not a fourth LQR state

- Common torque and differential torque are decoupled in the linearization, so
  steering is a separate one-state loop reusing the same `discrete_lqr()`.
- Adding a fourth state to `STATE_NAMES` would have broken the firmware export
  contract and changed the committed balance gain. Not worth it for a channel
  that does not couple.
- Consequence: the balance gain is still exactly
  `[61.8993272, 9.56442891, 13.0267381]`, byte-identical to before.

## Design decision: no track width anywhere in the controller

Three numbers for the same physical quantity, disagreeing by 40 percent:

| value | source |
|---|---|
| 0.517 m | CAD body origins (`left_wheel` y = -0.009, `right_wheel` y = +0.508) |
| 0.583 m | compiled tire contact patch separation (measured off the compiled model: 0.584 m) |
| 0.351 m | Batch 2 differential-yaw response, `aggregation.json: effective_track_width_estimate_m = 0.351004`, gantry-biased |

- Rather than pick one, `linearize_yaw_dynamics()` identifies the scalar yaw
  plant `w[k+1] = a*w[k] + b*d[k]` by finite difference on the model, the same
  technique already used for the balance A/B.
- Measured values: `a_yaw = 0.8752`, `b_yaw = +0.0337`.
- Spin-up uses torque, not a written-in yaw-rate initial condition, precisely
  because writing one would require a track width to keep body and wheel
  velocities consistent.
- `a_yaw` is clamped: anything outside `(0, 1]` falls back to `1.0`, an undamped
  integrator, which asks the design to work harder than the real plant will.
- Yaw rate comes straight off `imu_gyro[1]`, never from differencing wheels, for
  the same no-track-width reason.

## The real bug: the model's wheel names are backwards

- Symptom: the identified `b_yaw` came out **negative**, contradicting a hand
  derivation.
- Cause, confirmed in `sim/generated/seeded/latest/finn.seeded.sim.xml` line 67
  and 75: `motor_left_wheel` drives the body at world y = **-0.009**, and
  `motor_right_wheel` drives the one at y = **+0.508**. Robot +y is left. The
  names come from the CAD export.
- Why nothing caught it earlier: balance sends both wheels the *same* torque.
  Steering is the first feature in the repo that needs them to differ. The bug
  had been sitting in the model harmlessly since the model existed.
- Fix per hard rule 2 (signs live in the contract, never as a compensating
  negation at a call site): `config/finn_conventions.yaml` gained
  `yaw.sim_left_actuator_yaw_sign: -1`.
- Pinned by `test_positive_yaw_torque_turns_the_model_left`, which applies +0.3
  N.m of differential torque for 40 ticks and asserts the *world* quaternion
  rotates counter-clockwise. It pins against measured model behaviour, not
  against the actuator names, which is the whole point.
- Open question worth a look: `real_left_actuator_yaw_sign` is also `-1` in the
  conventions file, even though the surrounding comment says the physical robot
  is not mirrored and its controllers are labelled correctly. It carries its own
  bench check (`yaw_direction_bench_verified: false`), so nothing is unsafe, but
  the value and the comment do not obviously agree.

## Design decision: balance has torque priority

- `allocate_wheel_torques(tau_balance, tau_yaw, limit)` clamps balance first,
  then gives yaw only `limit - abs(tau_common)`.
- The naive alternative, summing then clamping per wheel, lets a turn request eat
  balance authority *asymmetrically*. That is a fall.
- Property under this rule: a saturated balance loop steers not at all. Tested
  directly: `allocate_wheel_torques(2.0, 5.0, 1.0)` returns `(1.0, 0.0)`.
- `test_no_allocation_can_put_a_wheel_outside_the_envelope` parametrizes five
  hostile pairs and asserts both wheel commands land inside the envelope by
  construction.

## Design decision: the accel slew limit is safety, not smoothing

- Holding forward acceleration `a` costs a steady lean of `atan(a/g)`.
- The reviewed firmware pitch fault is `kMaxAbsPitchRad = 10 degrees`, so
  acceleration is physically capped at `g*tan(10 deg) = 1.73 m/s^2` before Finn
  faults out. No command layer can change that.
- Default `forward_accel_limit_m_s2 = 0.5` leans `atan(0.5/9.81) = 2.9 degrees`,
  leaving the rest of the 10 degree budget for disturbance rejection.
- This is the nicest fact from the whole session: a rate limiter whose value is
  derived from a fault threshold, not from feel.

## Tuning, all measured

Yaw gain sweep, `--drive-profile spin`, 1.5 rad/s command, reproduced today:

| `--q-yaw` | gain | settled yaw rate | error | settled `tau_yaw` |
|---|---|---|---|---|
| 4 | 0.4675 | 0.703 rad/s | 53% | 0.372 N.m |
| 100 | 5.7142 | 1.431 rad/s | 5% | 0.384 N.m |

- The steady differential torque is ~0.38 N.m *regardless of gain*. That is the
  friction load, not a controller property. Recognising that is what made the low
  gain obviously wrong rather than arguably conservative: the loop was not
  fighting inertia, it was failing to overcome a constant.
- Default set to `--q-yaw 100`, exported as `kGainYawRate = 5.71421979f`.

Max yaw rate sweep:

- At 1.5 rad/s, spinning couples into fore-aft motion. Reproduced: the spin
  profile at 1.5 rad/s with q=100 gives `vel_track_p95 = 0.296`, which **fails**
  the 0.25 gate, while yaw tracking is fine at 0.074.
- At the 1.0 rad/s default the same profile passes: `vel_track_p95 = 0.142`,
  `yaw_track_p95 = 0.071`.
- The in-code note records the settled forward-velocity spread growing from 0.22
  to 0.30 m/s between the two.
- Default set to `max_yaw_rate_rad_s = 1.0`, which is still 360 degrees in 6.3 s.
- This is the balance-priority principle applied to picking an envelope rather
  than to allocating a torque.

## Two mistakes worth recording

**Duplicated default silently shadowed the new one.**

- `drive_lqr_sim.py` had its own `--q-yaw` default of 4.0 while `run_lqr_sim.py`
  had the new 100.0. Changing the gain appeared to do nothing.
- Caught by noticing the reported differential torque exactly matched the OLD
  gain times the error. Arithmetic on a telemetry column found it, not reading.
- Fixed by single-sourcing every drive argument into
  `run_lqr_sim.add_drive_arguments()`, which `drive_lqr_sim.parse_args` now calls.
  `drive_lqr_sim.py` defines zero drive defaults of its own.

**A diagnostic that "proved" odometry was broken was itself broken.**

- The diagnostic measured the velocity of the model's *origin* body. The wheel
  midline sits at y = (-0.009 + 0.508)/2 = 0.2495 m; the root body origin sits at
  y = 0. (`finn_measurements.yaml: com_lateral_m = 0.24903644` is the same
  offset.)
- So while the robot pivoted in place, the point being measured traced a circle
  of radius 0.25 m and reported a healthy forward velocity.
- Odometry had been accurate the entire time.
- Lesson: before concluding an estimator is broken, check *what point* the
  reference measurement is attached to.

## Pass-gate design

The original station-keeping gate (`max_abs_position_error < 0.25` and
`final_abs_position_error < 0.10`) fails every successful drive, because a
driven rollout is not trying to hold a spot. Driven rollouts are judged on
command tracking instead: `velocity_tracking_p95 < 0.25` and
`yaw_tracking_p95 < 0.40`. Two refinements were needed:

- **Only score settled samples.** `settled_tracking_error()` requires the command
  to have been unchanged for `COMMAND_SETTLE_S = 1.5` s. Scoring the slew ramps
  flags the rate limiter for doing exactly its job.
- **95th percentile, not max.** A hard spin makes the tires stick and slip, and
  odometry reads a slip as a momentary spurious forward velocity that no
  controller could command away. The max is reported alongside so genuine
  transients stay visible: the `square` profile reports
  `vel_track_p95=0.069 (max 0.071)`, the default `spin` reports
  `vel_track_p95=0.142 (max 0.353)`, and that gap is the slip.

## Firmware export: additive by construction

- `lqr_seeded_config.h` gained 11 new constants across 15 added lines (3 comment
  lines and a blank). Note: not "15 constants".
- All **20** pre-existing constants are byte-identical. Verified by diffing lines
  1-25 of the old and new header.
- New: `kYawAxis`, `kYawSign`, `kGainYawRate`, `kRealLeftActuatorYawSign`,
  `kMaxForwardVelMS`, `kMaxYawRateRadS`, `kDriveAccelLimitMS2`,
  `kDriveYawAccelLimitRadS2`, `kCommandTimeoutMs`, `kRefPositionBandM`,
  `kYawDirectionBenchVerified`.
- Exported now, consumed by nothing. The reason is in
  `test_the_drive_envelope_reaches_the_firmware_header`: exporting now keeps the
  later firmware port a firmware-only change instead of creating a second place
  to tune a robot.
- `kCommandTimeoutMs = 500` is bounded by a test against the 10 Hz host command
  rate: at least 3 and at most 10 missed messages. It covers a *different*
  failure from `kHeartbeatTimeoutMs = 300`: the heartbeat covers the link dying,
  the command timeout covers the link staying healthy while whatever produces
  commands stalls.

## Verification

- `uv run pytest -q`: **190 passed in 4.38s**.
- `uv run ruff check .`: clean. `ruff format --check`: 49 files already formatted.
- PlatformIO is not installed on this machine, so `pio run` could not be run. The
  headers were instead compile-checked directly with
  `clang++ -std=c++17 -fsyntax-only`, including the two `static_assert`s from
  `main.cpp` (`kHardTorqueLimitNm <= kTorqueLimitNm`, `kControlPeriodUs == 10000`).
  Both hold. `lqr_safety_config.h` needs a `PI` shim outside Arduino.
- End-to-end: `drive_lqr_sim.py --drive-profile square --no-viewer` passes with
  `max_abs_pitch_rad=0.118`, `max_abs_wheel_cmd_nm=1.000`.

## What blocks real-robot driving

Three gates, documented in `docs/real_lqr_bringup.md` Stage 3, in order:

1. **Finn has not balanced unsupported yet.** Both arming
   `*_bench_verified` flags are still `false`. Steering a robot that has not
   stood up is not a meaningful experiment.
2. **The reviewed safety envelope forbids driving, correctly.**
   `kMaxWheelTravelRev = 2.0` faults at about 1.02 m of travel
   (2 rev x 2*pi x 0.081 m), and `kFirstTrialDurationMs = 3000` ends the trial at
   3 s. Any real drive attempt trips a limit within a second or two. Driving
   needs its own reviewed limit block, set from short-balance-trial evidence.
3. **`kMaxAbsPitchRad = 10 degrees` caps sustained acceleration** at 1.73 m/s^2
   no matter what the command layer permits.

When those clear, the port is mechanical because the layering already matches:
`runControllerTick()` is already always-on and already independent of serial
input. What it needs is a command arbiter struct beside
`last_target_forward_vel_m_s` (main.cpp:160), `sendBalanceTorque` (main.cpp:302)
widened to `sendWheelTorques(tau_common, tau_yaw)` with the same headroom
allocation, a `DRIVE <v> <w>` branch in `handleCommand` (main.cpp:687, and the
first numeric parsing in any sketch in this repo), and a `schema,lqr_v2` bump
with `config/viz/finn_lqr.yaml` updated in the same commit. The two
`SetPosition` calls already cost up to 6 ms of the 10 ms control budget;
steering changes their values, not their count.

## Bench check added

`docs/real_lqr_bringup.md` Stage 1 gained step 5: with Finn held and motors
stopped, rotate left (counter-clockwise from above) and confirm `yaw_rate_rad_s`
goes positive, then set `imu.yaw_direction_bench_verified: true`. It fits in the
existing 15 second window. Unlike the other two flags it gates only the drive
layer, not arming, so it can be deferred.

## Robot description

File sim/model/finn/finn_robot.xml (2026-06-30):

<?xml version="1.0" ?>
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
<mujoco model="finn">
  <compiler angle="radian" meshdir="assets" autolimits="true"/>
  <default>
    <default class="finn">
      <joint frictionloss="0.1" armature="0.005"/>
      <position kp="50" dampratio="1"/>
      <default class="visual">
        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
      </default>
      <default class="collision">
        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
      </default>
    </default>
  </default>
  <worldbody>
    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
    <body name="base_2" pos="0 0 0" quat="1 0 0 0" childclass="finn">
      <inertial pos="-0.0125903 0.248567 0.347009" mass="3.99899" fullinertia="0.405206 0.375974 0.034759 0.000116582 0.00733655 -0.00106291"/>
      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
      <body name="left_wheel" pos="6.49924e-05 -0.009 0.04" quat="0.707107 -0.707107 -0 -0">
        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
        <joint axis="0 0 1" name="left_wheel"/>
        <inertial pos="8.622e-09 -8.622e-09 -0.0329857" mass="2.02455" fullinertia="0.00335882 0.00335882 0.00560974 -1e-12 -4.49e-10 4.49e-10"/>
        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
      </body>
      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
      <body name="right_wheel" pos="3.24608e-05 0.508 0.04" quat="0.645101 0.645101 -0.28956 0.28956">
        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
        <joint axis="0 0 1" name="right_wheel"/>
        <inertial pos="8.622e-09 -8.622e-09 -0.0329857" mass="2.02455" fullinertia="0.00335882 0.00335882 0.00560974 -1e-12 -4.49e-10 4.49e-10"/>
        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
      </body>
    </body>
  </worldbody>
  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
  <actuator>
    <position class="finn" name="left_wheel" joint="left_wheel"/>
    <position class="finn" name="right_wheel" joint="right_wheel"/>
  </actuator>
  <equality/>
</mujoco>

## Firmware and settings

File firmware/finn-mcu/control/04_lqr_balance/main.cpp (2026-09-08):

#include <Arduino.h>
#include <Wire.h>
#include <Adafruit_BNO08x.h>
#include <MoteusTeensy.h>
#include <sh2.h>

#include <math.h>
#include <stdlib.h>
#include <string.h>

#include "control_math.h"
#include "lqr_safety_config.h"
#include "lqr_seeded_config.h"

namespace {

// First unsupported-floor LQR bring-up firmware. The robot must be held by an
// operator for ZERO UPRIGHT, convention checking, release, and catch. Active
// control requires a host heartbeat and stops after one short trial.
//
// The balance loop runs every tick and depends on nothing above it. The command
// layer below it shapes a bounded reference and can never reach torque directly;
// docs/codebase-notes.md states the invariants it has to preserve.

constexpr uint32_t kSerialBaud = 115200;
constexpr uint8_t kImuSdaPin = 18;
constexpr uint8_t kImuSclPin = 19;
constexpr uint8_t kBno08xPrimaryAddress = 0x4A;
constexpr uint8_t kBno08xSecondaryAddress = 0x4B;
constexpr uint32_t kI2cClockHz = 100000;
constexpr uint32_t kI2cFallbackClockHz = 400000;
constexpr uint32_t kImuReportIntervalUs = 10000;
constexpr uint32_t kImuFreshTimeoutUs = 100000;
constexpr uint32_t kImuAliveTimeoutUs = 250000;
constexpr uint32_t kImuFirstSampleTimeoutUs = 2000000;

constexpr int8_t kLeftMoteusId = 1;
constexpr int8_t kRightMoteusId = 2;
constexpr uint32_t kCanArbitrationBitrate = 1000000;
constexpr uint16_t kMoteusMinReceiveWaitUs = 3000;
constexpr float kMoteusWatchdogTimeoutS = 0.05f;
constexpr uint8_t kMaxConsecutiveMoteusMisses = 3;

constexpr uint32_t kTelemetryPeriodUs = 10000;
constexpr uint32_t kIdleTelemetryPeriodUs = 1000000;
constexpr uint32_t kIdleStopPeriodUs = 100000;
constexpr uint32_t kMaxControlLagUs = 20000;
constexpr float kRadPerRev = 2.0f * PI;

static_assert(
    FinnLqrSafety::kHardTorqueLimitNm <= FinnLqrSeeded::kTorqueLimitNm,
    "real torque limit must not exceed the validated seeded-model limit");
static_assert(
    FinnLqrSeeded::kControlPeriodUs == 10000UL,
    "this firmware is intentionally reviewed for a 100 Hz controller");
static_assert(
    FinnLqrSafety::kMaxTrialDurationMs <= FinnLqrSafety::kFirstTrialDurationMs,
    "an operator must not be able to select a trial longer than the reviewed one");
static_assert(
    FinnLqrSafety::kControlBudgetUs < FinnLqrSeeded::kControlPeriodUs,
    "the control budget has to fit inside one control period");

float wrapPi(float value) {
  while (value > PI) value -= 2.0f * PI;
  while (value < -PI) value += 2.0f * PI;
  return value;
}

const FinnLqrControl::CommandLimits kCommandLimits = {
    FinnLqrSeeded::kMaxForwardVelMS,
    FinnLqrSeeded::kMaxYawRateRadS,
    FinnLqrSeeded::kDriveAccelLimitMS2,
    FinnLqrSeeded::kDriveYawAccelLimitRadS2,
    FinnLqrSeeded::kCommandTimeoutMs,
};

ACAN_T4FD_Settings can_settings(kCanArbitrationBitrate, DataBitRateFactor::x1);
MoteusTeensyCanFD can_bus(ACAN_T4::can3, can_settings);

Moteus::Options moteusOptions(const int8_t id) {
  Moteus::Options options;
  options.id = id;
  options.source = 0;
  options.disable_brs = true;
  options.default_query = true;
  options.min_rcv_wait_us = kMoteusMinReceiveWaitUs;
  options.query_format.mode = Moteus::kInt8;
  options.query_format.position = Moteus::kFloat;
  options.query_format.velocity = Moteus::kFloat;
  options.query_format.torque = Moteus::kFloat;
  options.query_format.voltage = Moteus::kFloat;
  options.query_format.temperature = Moteus::kFloat;
  options.query_format.fault = Moteus::kInt8;
  return options;
}

Moteus::PositionMode::Format torqueCommandFormat() {
  Moteus::PositionMode::Format format;
  format.position = Moteus::kFloat;
  format.velocity = Moteus::kFloat;
  format.feedforward_torque = Moteus::kFloat;
  format.kp_scale = Moteus::kFloat;
  format.kd_scale = Moteus::kFloat;
  format.maximum_torque = Moteus::kFloat;
  format.watchdog_timeout = Moteus::kFloat;
  return format;
}

Moteus left_moteus(can_bus, moteusOptions(kLeftMoteusId));
Moteus right_moteus(can_bus, moteusOptions(kRightMoteusId));
Moteus::PositionMode::Format torque_format = torqueCommandFormat();
using QueryValues = Moteus::Query::Result;

Adafruit_BNO08x bno08x(-1);
sh2_SensorValue_t imu_event;

struct ImuState {
  bool initialized = false;
  uint8_t address = 0;
  uint32_t clock_hz = 0;
  uint32_t last_any_event_us = 0;
  uint32_t last_quat_us = 0;
  float quat_real = 1.0f;
  float quat_i = 0.0f;
  float quat_j = 0.0f;
  float quat_k = 0.0f;
  float gyro_x_rad_s = 0.0f;
  float gyro_y_rad_s = 0.0f;
  float gyro_z_rad_s = 0.0f;
  float linear_accel_x_m_s2 = 0.0f;
  float linear_accel_y_m_s2 = 0.0f;
  float linear_accel_z_m_s2 = 0.0f;
  uint32_t reset_count = 0;
};

struct MoteusHealth {
  uint8_t consecutive_misses = 0;
};

ImuState imu;
MoteusHealth left_health;
MoteusHealth right_health;

enum class SystemState : uint8_t {
  kSafeIdle,
  kConventionCheck,
  kPreflight,
  kArmedIdle,
  kRunningLqr,
  kComplete,
  kFault,
};

SystemState state = SystemState::kSafeIdle;
char fault_reason[96] = "";
char serial_line[96] = "";
size_t serial_line_len = 0;

bool pitch_zero_valid = false;
float pitch_zero_raw_rad = 0.0f;
float start_left_pos_rev = 0.0f;
float start_right_pos_rev = 0.0f;
uint32_t state_start_ms = 0;
uint32_t arm_deadline_ms = 0;
uint32_t last_heartbeat_ms = 0;
uint32_t next_control_us = 0;
uint32_t next_telemetry_us = 0;
uint32_t next_idle_stop_us = 0;
uint32_t next_preflight_poll_us = 0;
uint32_t last_control_tick_us = 0;
uint32_t last_control_dt_us = 0;
uint32_t last_tick_duration_us = 0;
uint32_t trial_duration_ms = FinnLqrSafety::kFirstTrialDurationMs;

float last_left_command_nm = 0.0f;
float last_right_command_nm = 0.0f;
float last_balance_tau_raw_nm = 0.0f;
float last_balance_tau_nm = 0.0f;
float last_yaw_tau_nm = 0.0f;
float last_target_forward_vel_m_s = 0.0f;
float reference_forward_pos_m = 0.0f;
bool last_saturated = false;

// ---- Command layer (L2). Bounded reference only; never a torque. ----

// Held, clamped, and slew limited intent. A missing command and a crashed
// command source are the same event here: hold briefly, then ramp to zero.
// Ramping and not stepping is the point -- a step is itself a disturbance the
// balance loop would have to reject.
FinnLqrControl::CommandArbiter arbiter;

// ---- Arming preflight ----

struct PreflightStats {
  uint32_t start_ms = 0;
  uint32_t imu_quat_samples = 0;
  uint32_t imu_gyro_samples = 0;
  uint32_t imu_accel_samples = 0;
  uint32_t imu_reset_start = 0;
  float max_gyro_mag_rad_s = 0.0f;
  float max_quat_norm_error = 0.0f;
  float max_abs_pitch_error_rad = 0.0f;
  uint32_t poll_ticks = 0;
  uint32_t left_replies = 0;
  uint32_t right_replies = 0;
  uint32_t left_misses = 0;
  uint32_t right_misses = 0;
  uint8_t left_fault = 0;
  uint8_t right_fault = 0;
  float min_voltage_v = 1.0e9f;
  float max_voltage_v = -1.0e9f;
  float max_temp_c = -1.0e9f;
  float max_abs_wheel_vel_rev_s = 0.0f;
  bool encoders_finite = true;
  uint32_t telemetry_rows = 0;
  uint32_t max_tick_duration_us = 0;
};

PreflightStats preflight;
bool preflight_arms_on_pass = false;
uint8_t preflight_failures = 0;
uint8_t last_preflight_failures = 0;
bool last_preflight_valid = false;

const char* stateName() {
  switch (state) {
    case SystemState::kSafeIdle: return "safe_idle";
    case SystemState::kConventionCheck: return "convention_check";
    case SystemState::kPreflight: return "preflight";
    case SystemState::kArmedIdle: return "armed_idle";
    case SystemState::kRunningLqr: return "running_lqr";
    case SystemState::kComplete: return "complete";
    case SystemState::kFault: return "fault";
  }
  return "unknown";
}

const char* phaseName() {
  switch (state) {
    case SystemState::kConventionCheck: return "convention_check";
    case SystemState::kPreflight: return "preflight";
    case SystemState::kArmedIdle: return "armed_wait";
    case SystemState::kRunningLqr: return "balance";
    case SystemState::kComplete: return "complete";
    case SystemState::kFault: return "fault";
    default: return "idle";
  }
}

bool isRunning() { return state == SystemState::kRunningLqr; }
bool isArmed() { return state == SystemState::kArmedIdle || isRunning(); }

void printEvent(const char* event, const char* detail) {
  Serial.printf(
      "event,%lu,%s,%s,%s\n",
      static_cast<unsigned long>(micros()), event, stateName(), detail);
}

uint32_t imuQuatAgeUs() {
  return imu.last_quat_us == 0 ? UINT32_MAX : micros() - imu.last_quat_us;
}

uint32_t imuAnyAgeUs() {
  return imu.last_any_event_us == 0 ? UINT32_MAX : micros() - imu.last_any_event_us;
}

bool isImuFresh() {
  return imu.initialized && imu.last_quat_us != 0 && imuQuatAgeUs() <= kImuFreshTimeoutUs;
}

bool isImuAlive() {
  return imu.initialized && imu.last_any_event_us != 0 && imuAnyAgeUs() <= kImuAliveTimeoutUs;
}

float sensorXRotationRad() {
  const float w = imu.quat_real;
  const float x = imu.quat_i;
  const float y = imu.quat_j;
  const float z = imu.quat_k;
  return atan2f(2.0f * (w * x + y * z), 1.0f - 2.0f * (x * x + y * y));
}

float pitchRad() {
  const float raw = sensorXRotationRad();
  if (!pitch_zero_valid) return FinnLqrSeeded::kPitchSign * raw;
  return FinnLqrSeeded::kPitchSign * wrapPi(raw - pitch_zero_raw_rad);
}

float pitchRateRadS() {
  return FinnLqrSeeded::kPitchSign * imu.gyro_x_rad_s;
}

float yawRateRadS() {
  return FinnLqrSeeded::kYawSign * imu.gyro_y_rad_s;
}

float quatNormError() {
  const float w = imu.quat_real;
  const float x = imu.quat_i;
  const float y = imu.quat_j;
  const float z = imu.quat_k;
  return fabsf(sqrtf(w * w + x * x + y * y + z * z) - 1.0f);
}

float gyroMagnitudeRadS() {
  const float x = imu.gyro_x_rad_s;
  const float y = imu.gyro_y_rad_s;
  const float z = imu.gyro_z_rad_s;
  return sqrtf(x * x + y * y + z * z);
}

float leftForwardPositionRev() {
  const QueryValues& left = left_moteus.last_result().values;
  return FinnLqrSeeded::kRealLeftEncoderForwardSign *
         static_cast<float>(left.position - start_left_pos_rev);
}

float rightForwardPositionRev() {
  const QueryValues& right = right_moteus.last_result().values;
  return FinnLqrSeeded::kRealRightEncoderForwardSign *
         static_cast<float>(right.position - start_right_pos_rev);
}

float forwardPositionM() {
  return 0.5f * (leftForwardPositionRev() + rightForwardPositionRev()) *
         kRadPerRev * FinnLqrSeeded::kWheelRadiusM;
}

float forwardVelocityMS() {
  const QueryValues& left = left_moteus.last_result().values;
  const QueryValues& right = right_moteus.last_result().values;
  const float left_forward_rev_s = FinnLqrSeeded::kRealLeftEncoderForwardSign *
                                   static_cast<float>(left.velocity);
  const float right_forward_rev_s = FinnLqrSeeded::kRealRightEncoderForwardSign *
                                    static_cast<float>(right.velocity);
  return 0.5f * (left_forward_rev_s + right_forward_rev_s) *
         kRadPerRev * FinnLqrSeeded::kWheelRadiusM;
}

long heartbeatAgeMs() {
  return last_heartbeat_ms == 0 ? -1L : static_cast<long>(millis() - last_heartbeat_ms);
}

Moteus::PositionMode::Command torqueCommand(const float torque_nm) {
  Moteus::PositionMode::Command command;
  command.position = NaN;
  command.velocity = 0.0;
  command.feedforward_torque = FinnLqrControl::clampFloat(
      torque_nm, -FinnLqrSafety::kHardTorqueLimitNm, FinnLqrSafety::kHardTorqueLimitNm);
  command.kp_scale = 0.0;
  command.kd_scale = 0.0;
  command.maximum_torque = FinnLqrSafety::kHardTorqueLimitNm;
  command.watchdog_timeout = kMoteusWatchdogTimeoutS;
  return command;
}

void updateHealth(MoteusHealth& health, const bool ok) {
  if (ok) {
    health.consecutive_misses = 0;
  } else if (health.consecutive_misses < 255) {
    health.consecutive_misses++;
  }
}

bool sendAllStop() {
  last_left_command_nm = 0.0f;
  last_right_command_nm = 0.0f;
  const bool left_ok = left_moteus.SetStop();
  const bool right_ok = right_moteus.SetStop();
  updateHealth(left_health, left_ok);
  updateHealth(right_health, right_ok);
  return left_ok && right_ok;
}

void latchFault(const char* reason) {
  if (state == SystemState::kFault) return;
  strncpy(fault_reason, reason, sizeof(fault_reason) - 1U);
  fault_reason[sizeof(fault_reason) - 1U] = '\0';
  sendAllStop();
  state = SystemState::kFault;
  state_start_ms = millis();
  printEvent("failsafe", fault_reason);
}

bool sendWheelTorques(const float tau_common_nm, const float tau_yaw_nm) {
  if (!FinnLqrControl::isFinite(tau_common_nm) || !FinnLqrControl::isFinite(tau_yaw_nm)) {
    latchFault("non_finite_torque_command");
    return false;
  }
  const float yaw_left = FinnLqrSeeded::kRealLeftActuatorYawSign * tau_yaw_nm;
  const float left_request =
      FinnLqrSeeded::kRealLeftCommonTorqueSign * tau_common_nm + yaw_left;
  const float right_request =
      FinnLqrSeeded::kRealRightCommonTorqueSign * tau_common_nm - yaw_left;
  if (!FinnLqrControl::isFinite(left_request) || !FinnLqrControl::isFinite(right_request)) {
    latchFault("non_finite_torque_command");
    return false;
  }
  const bool left_ok = left_moteus.SetPosition(torqueCommand(left_request), &torque_format);
  const bool right_ok = right_moteus.SetPosition(torqueCommand(right_request), &torque_format);
  updateHealth(left_health, left_ok);
  updateHealth(right_health, right_ok);
  if (left_health.consecutive_misses >= kMaxConsecutiveMoteusMisses) {
    latchFault("left_moteus_no_reply");
    return false;
  }
  if (right_health.consecutive_misses >= kMaxConsecutiveMoteusMisses) {
    latchFault("right_moteus_no_reply");
    return false;
  }
  last_left_command_nm = left_request;
  last_right_command_nm = right_request;
  return left_ok && right_ok;
}

bool configureImuReports() {
  bool ok = true;
  ok = bno08x.enableReport(SH2_ROTATION_VECTOR, kImuReportIntervalUs) && ok;
  ok = bno08x.enableReport(SH2_GYROSCOPE_CALIBRATED, kImuReportIntervalUs) && ok;
  ok = bno08x.enableReport(SH2_LINEAR_ACCELERATION, kImuReportIntervalUs) && ok;
  printEvent(ok ? "imu_reports_enabled" : "imu_report_failed", "rv_gyro_linear_accel_100hz");
  return ok;
}

void serviceImu();

bool waitForFirstImuSample() {
  const uint32_t start_us = micros();
  while (!isImuFresh() && micros() - start_us < kImuFirstSampleTimeoutUs) {
    serviceImu();
    delay(1);
  }
  return isImuFresh();
}

bool initImuAtAddress(const uint8_t address) {
  if (!bno08x.begin_I2C(address, &Wire)) return false;
  Wire.setClock(imu.clock_hz);
  if (!configureImuReports()) {
    sh2_close();
    return false;
  }
  imu.initialized = true;
  imu.address = address;
  imu.last_any_event_us = 0;
  imu.last_quat_us = 0;
  if (!waitForFirstImuSample()) {
    imu.initialized = false;
    sh2_close();
    return false;
  }
  return true;
}

bool initImu() {
  Wire.setSDA(kImuSdaPin);
  Wire.setSCL(kImuSclPin);
  Wire.begin();
  const uint32_t clocks[] = {kI2cClockHz, kI2cFallbackClockHz};
  const uint8_t addresses[] = {kBno08xPrimaryAddress, kBno08xSecondaryAddress};
  for (const uint32_t clock_hz : clocks) {
    imu.clock_hz = clock_hz;
    Wire.setClock(clock_hz);
    delay(500);
    for (const uint8_t address : addresses) {
      if (initImuAtAddress(address)) {
        Serial.printf(
            "event,%lu,imu_initialized,address_0x%02X,clock_%lu\n",
            static_cast<unsigned long>(micros()), address,
            static_cast<unsigned long>(clock_hz));
        return true;
      }
    }
  }
  printEvent("imu_failed", "no_fresh_reports_at_0x4A_or_0x4B");
  return false;
}

void serviceImu() {
  if (!imu.initialized) return;
  if (bno08x.wasReset()) {
    imu.reset_count++;
    imu.last_any_event_us = 0;
    imu.last_quat_us = 0;
    if (!configureImuReports() && isRunning()) {
      latchFault("imu_report_reenable_failed");
      return;
    }
    printEvent("imu_reset", "reports_reenabled");
  }

  const bool sampling = state == SystemState::kPreflight;
  for (uint8_t i = 0; i < 8; ++i) {
    if (!bno08x.getSensorEvent(&imu_event)) break;
    const uint32_t event_us = micros();
    imu.last_any_event_us = event_us;
    if (imu_event.sensorId == SH2_ROTATION_VECTOR) {
      const auto& quat = imu_event.un.rotationVector;
      imu.quat_real = quat.real;
      imu.quat_i = quat.i;
      imu.quat_j = quat.j;
      imu.quat_k = quat.k;
      imu.last_quat_us = event_us;
      if (sampling) {
        preflight.imu_quat_samples++;
        const float norm_error = quatNormError();
        if (norm_error > preflight.max_quat_norm_error) {
          preflight.max_quat_norm_error = norm_error;
        }
        const float pitch_error = fabsf(pitchRad() - FinnLqrSeeded::kTargetPitchRad);
        if (pitch_error > preflight.max_abs_pitch_error_rad) {
          preflight.max_abs_pitch_error_rad = pitch_error;
        }
      }
    } else if (imu_event.sensorId == SH2_GYROSCOPE_CALIBRATED) {
      const auto& gyro = imu_event.un.gyroscope;
      imu.gyro_x_rad_s = gyro.x;
      imu.gyro_y_rad_s = gyro.y;
      imu.gyro_z_rad_s = gyro.z;
      if (sampling) {
        preflight.imu_gyro_samples++;
        const float magnitude = gyroMagnitudeRadS();
        if (magnitude > preflight.max_gyro_mag_rad_s) {
          preflight.max_gyro_mag_rad_s = magnitude;
        }
      }
    } else if (imu_event.sensorId == SH2_LINEAR_ACCELERATION) {
      const auto& accel = imu_event.un.linearAcceleration;
      imu.linear_accel_x_m_s2 = accel.x;
      imu.linear_accel_y_m_s2 = accel.y;
      imu.linear_accel_z_m_s2 = accel.z;
      if (sampling) preflight.imu_accel_samples++;
    }
  }
}

bool checkMoteusPreflight() {
  if (!sendAllStop()) return false;
  const QueryValues& left = left_moteus.last_result().values;
  const QueryValues& right = right_moteus.last_result().values;
  return left.fault == 0 && right.fault == 0;
}

bool checkActiveSafety() {
  if (!isImuAlive()) {
    latchFault("imu_no_reports");
    return false;
  }
  if (!isImuFresh()) {
    latchFault("imu_quaternion_stale");
    return false;
  }
  if (last_heartbeat_ms == 0 || millis() - last_heartbeat_ms > FinnLqrSafety::kHeartbeatTimeoutMs) {
    latchFault("host_heartbeat_timeout");
    return false;
  }

  const QueryValues& left = left_moteus.last_result().values;
  const QueryValues& right = right_moteus.last_result().values;
  const FinnLqrControl::ActiveControlState active_control_state = {
      imu.quat_real,
      imu.quat_i,
      imu.quat_j,
      imu.quat_k,
      imu.gyro_x_rad_s,
      imu.gyro_y_rad_s,
      pitch_zero_raw_rad,
      static_cast<float>(left.position),
      static_cast<float>(left.velocity),
      static_cast<float>(left.temperature),
      static_cast<float>(right.position),
      static_cast<float>(right.velocity),
      static_cast<float>(right.temperature),
      start_left_pos_rev,
      start_right_pos_rev,
      reference_forward_pos_m,
  };
  if (!FinnLqrControl::activeControlStateIsFinite(active_control_state)) {
    latchFault("non_finite_active_state");
    return false;
  }
  if (fabsf(pitchRad()) > FinnLqrSafety::kMaxAbsPitchRad) {
    latchFault("pitch_limit");
    return false;
  }
  if (left.fault != 0 || right.fault != 0) {
    latchFault("moteus_fault");
    return false;
  }
  if (left.temperature >= FinnLqrSafety::kMaxMoteusTempC ||
      right.temperature >= FinnLqrSafety::kMaxMoteusTempC) {
    latchFault("moteus_overtemp");
    return false;
  }
  if (fabsf(static_cast<float>(left.velocity)) >= FinnLqrSafety::kMaxWheelSpeedRevS ||
      fabsf(static_cast<float>(right.velocity)) >= FinnLqrSafety::kMaxWheelSpeedRevS) {
    latchFault("wheel_speed_limit");
    return false;
  }
  if (fabsf(leftForwardPositionRev()) >= FinnLqrSafety::kMaxWheelTravelRev ||
      fabsf(rightForwardPositionRev()) >= FinnLqrSafety::kMaxWheelTravelRev) {
    latchFault("wheel_travel_limit");
    return false;
  }
  return true;
}

void completeTrial(const char* reason) {
  sendAllStop();
  state = SystemState::kComplete;
  state_start_ms = millis();
  printEvent("lqr_complete", reason);
}
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
void loop() {
  serviceSerial();
  serviceImu();
  servicePreflight();
  serviceStateTimeouts();

  const uint32_t now_us = micros();
  if (isRunning() && static_cast<int32_t>(now_us - next_control_us) >= 0) {
    if (now_us - next_control_us > kMaxControlLagUs) {
      latchFault("control_deadline_missed");
    }
    next_control_us += FinnLqrSeeded::kControlPeriodUs;
    runControllerTick();
  }

  const bool high_rate =
      isRunning() || state == SystemState::kConventionCheck || state == SystemState::kPreflight;
  const uint32_t telemetry_period_us = high_rate ? kTelemetryPeriodUs : kIdleTelemetryPeriodUs;
  if (static_cast<int32_t>(now_us - next_telemetry_us) >= 0) {
    next_telemetry_us = now_us + telemetry_period_us;
    printTelemetry();
  }

  serviceIdleStop();
  serviceLed();
}

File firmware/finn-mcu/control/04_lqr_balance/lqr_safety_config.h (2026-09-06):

#pragma once

// Human-reviewed limits for the first unsupported floor trials. These are kept
// separate from the generated LQR gain so changing the model never silently
// relaxes a real-robot safety boundary.
namespace FinnLqrSafety {
// Raised from the 0.25 N*m Batch 1 bench cap on 2026-08-05. That cap was carried
// into the model by accident rather than chosen, and it sits below the torque this
// robot physically needs to stay upright: with both wheels capped there, gravity
// wins past 2.7 degrees of lean. At 1.0 N*m per wheel the sim recovers roughly 11
// degrees, which covers kMaxStartPitchErrorRad with margin, while holding chassis
// acceleration near 3 m/s^2 so a fault cannot launch the robot across the room.
// The hub motors can deliver far more; that authority stays unused for now.
constexpr float kHardTorqueLimitNm = 1.0f;
// Keep the fault limit inside the recoverable envelope. A limit wider than what the
// controller can arrest is not protection, it just lets the robot flail before it
// gives up.
constexpr float kMaxAbsPitchRad = 10.0f * PI / 180.0f;
constexpr float kMaxStartPitchErrorRad = 8.0f * PI / 180.0f;
constexpr float kMaxStartWheelSpeedRevS = 0.15f;
constexpr float kMaxWheelSpeedRevS = 2.5f;
constexpr float kMaxWheelTravelRev = 2.0f;
constexpr float kMaxMoteusTempC = 60.0f;
constexpr unsigned long kArmTimeoutMs = 10000UL;
constexpr unsigned long kHeartbeatTimeoutMs = 300UL;
constexpr unsigned long kFirstTrialDurationMs = 3000UL;
// TRIAL <ms> clamps to this. Shipped equal to kFirstTrialDurationMs so the
// envelope an operator can select is exactly the envelope that was reviewed.
// Raising it is a deliberate decision made from completed short trials, not a
// convenience: every limit below was sized for a 3 s catch.
constexpr unsigned long kMaxTrialDurationMs = kFirstTrialDurationMs;
constexpr unsigned long kMinTrialDurationMs = 500UL;
constexpr unsigned long kConventionCheckDurationMs = 15000UL;

// ---- Arming preflight ----
// ARM FINN spends this window with the motors commanded stopped, sampling every
// subsystem at the control rate before it will arm. It measures the CAN and IMU
// paths the control loop actually uses rather than checking them once, because
// the failures that matter here are intermittent: a marginal I2C pull-up, a CAN
// termination fault, a pack that sags only under query load.
constexpr unsigned long kPreflightDurationMs = 2000UL;
// The BNO085 is configured for 100 Hz reports. Below 80 Hz the estimator is
// running on stale attitude for whole control ticks.
constexpr float kMinImuReportRateHz = 80.0f;
constexpr float kMinTelemetryRateHz = 80.0f;
constexpr float kMinMoteusReplyRateHz = 80.0f;
// The operator holds Finn still through preflight, so anything above this is
// either a shaking hand or a gyro that is not actually reporting rest.
constexpr float kMaxPreflightGyroRadS = 0.15f;
constexpr float kMaxQuatNormError = 0.02f;
// Start cold enough that the 60 C run limit is not reachable inside one trial.
constexpr float kMaxPreflightTempC = 50.0f;
// A stopped-motor bus should not sag at all; movement here means a failing pack,
// a loose lug, or a connector that will drop out under balance current.
constexpr float kMaxPreflightVoltageSagV = 0.5f;
// No bus voltage is specified anywhere in the repo, so this check reports the
// measured value and is skipped rather than guessed at. Set it from the pack
// spec to turn the floor into a gate.
constexpr float kMinBusVoltageV = 0.0f;
// Leaves 2 ms of the 10 ms control period. The two moteus SetPosition calls
// already dominate this budget; a third CAN transaction does not fit.
constexpr uint32_t kControlBudgetUs = 8000UL;

// ---- Drive layer ----
// The command layer below the balance loop is built and tested, but no drive
// command is accepted while this is false, and yaw torque is held at exactly
// zero. Three separate things gate driving and none of them are cleared:
// Finn has not balanced unsupported, yaw_direction_bench_verified is false, and
// kMaxWheelTravelRev faults at about 1.02 m of travel with kFirstTrialDurationMs
// ending the run at 3 s. Driving needs its own reviewed limits, set from balance
// trial evidence. See Stage 3 in docs/real_lqr_bringup.md.
constexpr bool kDriveEnabled = false;
}  // namespace FinnLqrSafety

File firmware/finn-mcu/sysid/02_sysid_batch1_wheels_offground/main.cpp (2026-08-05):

#include <Arduino.h>
#include <Wire.h>
#include <Adafruit_BNO08x.h>
#include <MoteusTeensy.h>
#include <sh2.h>

#include <math.h>
#include <string.h>

namespace {

// Finn sysid in a wheels off ground test (batch 01)
// must send "ARM FINN" then "RUN BATCH1" commands for execution.


constexpr uint32_t kSerialBaud = 115200; //usb baud
constexpr uint8_t kImuSdaPin = 18; //teensy i2c pins for the imu
constexpr uint8_t kImuSclPin = 19; // ^^
constexpr uint8_t kBno08xPrimaryAddress = 0x4A; //possible imu addresses over i2c
constexpr uint8_t kBno08xSecondaryAddress = 0x4B; //^^^
constexpr uint32_t kI2cClockHz = 100000; // standard-mode i2c; BNO08x is more reliable here on Teensy 4.1
constexpr uint32_t kI2cFallbackClockHz = 400000; // faster diagnostic fallback
constexpr uint32_t kImuReportIntervalUs = 10000;  // 100hz rotation vector
constexpr uint32_t kImuTimeoutUs = 250000; //if no IMU sample arrives for 250 ms the IMU is considered "stale."
constexpr uint32_t kImuPowerSettleMs = 500;
constexpr uint32_t kImuFirstSampleTimeoutUs = 2000000;
constexpr uint32_t kMaxIgnoredImuEventPrints = 5;

constexpr int8_t kLeftMoteusId = 1; //canid's
constexpr int8_t kRightMoteusId = 2;
constexpr uint32_t kCanArbitrationBitrate = 1000000;
constexpr uint16_t kMoteusMinReceiveWaitUs = 3000; // controller reply timeout
constexpr float kHardTorqueLimitNm = 0.25f; // absolute torque ceiling enforcement
constexpr float kMoteusWatchdogTimeoutS = 0.05f; //50ms self stop without fresh command
constexpr uint8_t kMaxConsecutiveMoteusMisses = 3; // fault limit on missed commands
constexpr float kMaxMoteusTempC = 60.0f; // conservative first-run cutoff.
constexpr uint32_t kMaxBatchElapsedMs = 420000; // top-level guard; scripted max is about 294s.

constexpr uint32_t kControlPeriodUs = 10000;    // 100 Hz command loop.
constexpr uint32_t kTelemetryPeriodUs = 10000;  // 100 Hz CSV log stream while running.
constexpr uint32_t kIdleTelemetryPeriodUs = 1000000;  // 1 Hz idle/status heartbeat.
constexpr uint32_t kIdleStopPeriodUs = 1000000;  // Reassert stop at 1 Hz when idle/faulted.
constexpr float kMotionVelocityRevS = 0.02f;
constexpr float kMotionPositionRev = 0.01f;

// The official mjbots Teensy example uses 1 Mbps arbitration and data rate
// with BRS disabled. That is intentionally conservative for early bringup.
ACAN_T4FD_Settings can_settings(kCanArbitrationBitrate, DataBitRateFactor::x1);
MoteusTeensyCanFD can_bus(ACAN_T4::can3, can_settings); //wraps pins 30-31 in moteus adapter

Moteus::Options moteusOptions(const int8_t id) {
  Moteus::Options options;
  options.id = id;
  options.source = 0;
  options.disable_brs = true;
  options.default_query = true; // ask controller to report state back
  options.min_rcv_wait_us = kMoteusMinReceiveWaitUs;

  options.query_format.mode = Moteus::kInt8; //which reply fields come back + precision
  options.query_format.position = Moteus::kFloat;
  options.query_format.velocity = Moteus::kFloat;
  options.query_format.torque = Moteus::kFloat;
  options.query_format.voltage = Moteus::kFloat;
  options.query_format.temperature = Moteus::kFloat;
  options.query_format.fault = Moteus::kInt8;
  return options;
}

// Fields actually sent in a position command, and their wire precision.
Moteus::PositionMode::Format torqueCommandFormat() {
  Moteus::PositionMode::Format format;
  format.position = Moteus::kFloat;
  format.velocity = Moteus::kFloat;
  format.feedforward_torque = Moteus::kFloat;
  format.kp_scale = Moteus::kFloat;
  format.kd_scale = Moteus::kFloat;
  format.maximum_torque = Moteus::kFloat;
  format.watchdog_timeout = Moteus::kFloat;
  return format;
}

Moteus left_moteus(can_bus, moteusOptions(kLeftMoteusId)); //both controllers share the one can bus
Moteus right_moteus(can_bus, moteusOptions(kRightMoteusId));
Moteus::PositionMode::Format torque_format = torqueCommandFormat(); //cached once

Adafruit_BNO08x bno08x(-1); //imu driver, -1 = no reset pin wired
sh2_SensorValue_t imu_event; //reusable buffer the driver fills

struct ImuState { //latest imu reading + health
  bool initialized = false; //did begin + report setup succeed
  uint8_t address = 0; //which i2c addr answered
  uint32_t clock_hz = 0; //which bus speed worked
  uint32_t last_any_event_us = 0;
  uint32_t last_event_us = 0; //timestamp of last sample, also the freshness clock
  float quat_real = 1.0f; //orientation quaternion, 1,0,0,0 = identity
  float quat_i = 0.0f;
  float quat_j = 0.0f;
  float quat_k = 0.0f;
  float accuracy_rad = 0.0f; //reported heading accuracy
  uint32_t event_count = 0;
  uint32_t rotation_event_count = 0;
  uint32_t game_rotation_event_count = 0;
  uint32_t other_event_count = 0;
  uint32_t reset_count = 0; //times the chip spontaneously reset
};

ImuState imu;

struct MoteusHealth { //per controller link health
  uint32_t last_ok_us = 0; //last good reply
  uint8_t consecutive_misses = 0; //missed replies in a row
};

MoteusHealth left_health;
MoteusHealth right_health;

using QueryValues = Moteus::Query::Result; //shorthand for the controller reply struct

enum class SystemState : uint8_t { //master interlock
  kSafeIdle, //boot/safe, no motion
  kArmedIdle, //armed, motion allowed
  kRunningBatch1, //executing the batch
  kComplete, //finished
  kFault, //latched error, needs CLEAR
};

enum class SegmentMode : uint8_t { //what a script step does
  kStop, //hold both stopped
  kTorque, //constant torque for a fixed time
  kTorqueUntilMotion, //constant torque until breakaway/motion is detected
  kSpinupUntilVelocity, //drive until target speed
  kCoastUntilSlow, //release torque, watch it slow down
};

enum class WheelSelect : uint8_t { //which wheel's velocity gates the exit
  kNone,
  kLeft,
  kRight,
};

struct BatchSegment { //one row of the test script
  const char* name;
  SegmentMode mode;
  WheelSelect observed_wheel; //wheel watched for the exit condition
  uint32_t max_duration_ms; //hard time cap
  uint32_t min_duration_ms; //don't check the velocity exit before this
  float left_torque_nm;
  float right_torque_nm;
  float exit_abs_velocity_rev_s; //speed threshold for spinup/coast exit
};

constexpr BatchSegment makeSegment(const char* name, const SegmentMode mode,
                                   const WheelSelect observed_wheel,
                                   const uint32_t max_duration_ms,
                                   const uint32_t min_duration_ms,
                                   const float left_torque_nm,
                                   const float right_torque_nm,
                                   const float exit_abs_velocity_rev_s) {
  return BatchSegment{name, mode, observed_wheel, max_duration_ms, min_duration_ms,
                      left_torque_nm, right_torque_nm, exit_abs_velocity_rev_s};
}

enum class SegmentEndReason : uint8_t {
  kNone,
  kTimeout,
  kMotionReached,
  kSpeedReached,
  kSlowReached,
};
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

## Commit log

2026-05-22 firmware instantiation with teensy and PlatformIO
2026-05-23 bringup test 01 script for ensuring imu connection and can probed. Successful over 4 runs
2026-06-12 setup scaffolding for a post processng script to help build and verify the mujoco xml model for finn in sim
    [finn_robot.xml]
2026-06-12 added a bringup script for sysid work on the static gantry for finn, yet to run an integration test or the scripts data capture
2026-06-13 reworked the mcu bringup sketches into a sysid layout and built a reusable serial logging harness for capturing teensy runs
    one capture engine plus a thin batch1 preset that flashes the board, waits for it to re-enumerate, logs telemetry into timestamped run folders, and kicks off a postprocess summary. dropped the over-built yaml supervisor in favor of the lean engine and added tests for the capture logic. firmware moved from bringup/ to sysid/ and platformio points at the new paths
    [main.cpp, test_serial_log_capture.py]
2026-06-13 set up CI and cleaned a few things up
    added a github actions pipeline: one job lints, format-checks and tests the python side, another compiles and runs cppcheck on the firmware for the teensy on every push. it discovers all the platformio envs and tests on its own so new sketches and tests get covered without touching the workflow. compiling for teensy4.1 plus high severity cppcheck is the gate that should keep the firmware honest to the hardware
    also fixed the vscode gitignore so the shared editor config actually tracks (the .vscode/ rule was swallowing the re-includes), made the clangd toolchain path machine agnostic, dropped the stray .DS_Store files, and added a .env.example for the on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
    [check_env.py]
2026-06-20 added arm toolchain include paths to clangd config for clean ide diagnostics
2026-06-20 reworked batch 1 sysid firmware to dynamic computed segments, 100hz loop, breakaway detection, and temperature guard
    [main.cpp]
2026-06-20 built batch 1 postprocessor with physics fitting for motor inertia, friction, damping, and actuator tracking
2026-06-20 added batch 2 loaded ground-contact sysid firmware, capture wrapper, and postprocessor with batch 1 prior wiring
2026-06-20 fixed CI: gitignore platformio artifacts, ruff exclude vendor code, skip mujoco mesh test without generated assets, and format pass
    [postprocess_sysid_batch2.py, test_postprocess_mujoco.py, test_serial_log_capture.py]
2026-06-20 wired finn_measurements.yaml into sysid postprocessors and fixed source labels, path resolution, and com duplication
    [postprocess_sysid_batch2.py, test_serial_log_capture.py]
2026-06-22 fixed batch 2 imu axis analysis, gantry mass inputs, and loaded radius sign handling
    [postprocess_sysid_batch2.py, test_serial_log_capture.py]
2026-06-22 fixed bno08x i2c bringup for imu check and sysid batches
    [main.cpp]
2026-06-26 improve sysid batch imu telemetry and excitation
2026-06-30 remove open-loop batch3 replay path
    Open-loop Batch 3 is no longer the right validation gate now that the real robot needs the gantry to stay upright. A taut quickdraw measures fixture dynamics, while a slack quickdraw lets the robot fall before useful free-body data is collected.
    Keep the seeded MuJoCo export, STL-backed model layout, meshdir resolution, and generic capture callback for controlled LQR validation.
    [5b_wago_bracket.stl, base_rail.stl, battery_adapter.stl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]
2026-07-13 track generated seed model so the sim runs on a fresh clone
    run_lqr_sim.py and the MuJoCo tools default to
    sim/generated/seeded/latest/finn.seeded.sim.xml, but sim/generated/ was fully
    git-ignored, so a fresh checkout had no model and could not run the sim (the
    raw sysid logs needed to regenerate it are large and robot-specific, and stay
    out of git by design). Commit the 52 KB reference bundle plus its provenance,
    and narrow .gitignore to keep only that subtree while still ignoring other
    generated output. Also un-ignore the committed reference meshes so future STLs
    in sim/model/finn/assets/ aren't silently dropped.
    Add a minimal smoke test that loads the committed model and runs a short LQR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
    [test_run_lqr_sim_smoke.py]
2026-08-05 add shared agent guide and docs-sync skill
    CLAUDE.md documents repo structure, the measurements -> seeded model ->
    LQR gain -> firmware header derivation chain, per-area conventions, and
    the rules that protect generated artifacts and the hardware safety gates.
    AGENTS.md symlinks to it so every harness reads one file.
    finn-docs-sync keeps that guide matched to the repo as it grows, following
    the existing .agents canonical + .claude pointer skill layout.
2026-08-05 clean up comments across the tree
    Apply the earn-its-place rule from CLAUDE.md. Removed comments that restate
    the code they sit above: signal group labels that repeat the group: field in
    the scopik profile, print-section labels in check_env, part labels in the
    firmware sketches, and the stock PlatformIO boilerplate header.
    Removed the traces of how the code was written rather than what it does: the
    gitignore attribution header, a test banner referencing a past wiring pass,
    and first-person phrasing. Replaced em dashes with plain dashes throughout.
    Comments carrying a reason, a measurement, or an external contract are kept
    and in several files tightened: the CAN probe has no acking node, gi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
    [check_env.py, main.cpp, postprocess_sysid_batch2.py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]
2026-08-05 fix LQR plant identification and size the torque envelope
    The identified plant the LQR was designed against did not describe a
    balancing robot, and three separate defects fed into that.
    Ground contact. The model's authored rest pose floats the tires 3 mm
    above the floor, and set_reduced_state never settled it. A 3 mm fall
    takes 25 ms while the finite difference steps a single 10 ms tick, so
    every measurement was taken in free fall. A free-falling body feels no
    gravity torque about its COM, so pitch produced no pitch acceleration:
    A[1,0] came out 0, the controllability matrix was rank 2 of 3, and the
    LQR left a closed-loop pole at 1.0000000126. That marginal pole is a
    free integrator with no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
    [build_seeded_mujoco_model.py, finn_conventions.yaml, lqr_safety_config.h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]
2026-08-28 add live signal streaming to scopik
    Scopik does recorded, open-loop sim-to-real comparison, and its README kept
    live streaming out "until a real robot workflow requires them". Driving a
    balancing robot by hand is that workflow: a gap report written after the run
    cannot tell you what the robot is doing while you steer it.
    scopik.live is deliberately much smaller than the gap pipeline - no profile, no
    model, no comparison, just named scalars on a shared timeline. A row missing a
    declared column is skipped rather than raised, because a live sink must never be
    able to interrupt the control loop feeding it.
    All rerun calls stay inside rrlog/ as the package requires.
2026-08-28 add steerable control above the always-on LQR balance loop
    Drive Finn around from the keyboard, built so the firmware port is a
    translation rather than a redesign. The teleop is not really the point: it is
    the first tenant of a command layer that will later hold an HRI or navigation
    policy, and the layer is shaped so a slow, wild, or crashed tenant degrades to
    "no command" rather than to "no balance".
    Four layers, five invariants, each with a test named for it; docs/codebase-notes.md
    states them. A command source takes the clock and returns a bounded DriveCommand,
    and gets no MjData, no handles, and no gains, so it cannot reach a torque. The
    arbiter holds, clamps, slew-limits, and ramps sta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
    [drive_lqr_sim.py, finn_conventions.yaml, test_drive_lqr_sim.py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]
2026-09-06 add an arming preflight and a balance-run postprocessor
    ARM FINN no longer arms. It enters a two-second motors-stopped preflight that
    samples the IMU and the CAN bus at the control rate, emits one check, line per
    test, and arms only if every one passes. PREFLIGHT runs the same battery without
    arming so a failure can be chased off the arm path. Sampling over a window is the
    point: the failures that end a balance trial are intermittent, and a single-shot
    probe sees none of them.
    The host runs the check the firmware cannot. LiveIntegrityMonitor watches the
    schema tag, per-row column count, and non-finite values as they arrive, because
    the MCU has no way to know what reached the far end of the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
    [lqr_safety_config.h, main.cpp, test_finn_lqr_contract.py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]
2026-09-06 report the rotation-vector rate and stop crashing on a preflight-only run
    Two bugs the first hardware preflight found.
    write_report iterated actuator_tracking and loop_latency as per-key dicts, but
    both returned a bare verdict when the run was too short to fit anything. A
    preflight capture has no balance phase at all, so the very first thing anyone
    runs crashed the report writer. Both short-run paths now return the same shape
    they return on success.
    The integrity audit reported imu_fresh_fraction 1.0 on a run whose fused
    quaternion was arriving at 0.03 Hz. That column is isImuAlive(), which reads true
    on any report inside 250 ms, so a healthy gyro stream masks a dead rotation
    vector. isImu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
    [test_postprocess_lqr_balance.py]
2026-09-08 extract an importable finn package from the host scripts
    src/finn now holds the shared logic the tools were dynamically importing
    from each other: control (no MuJoCo dependency), simulation, lqr
    validation/export, reporting, model postprocess, and telemetry parsing.
    tools/*.py stay as thin CLI wrappers so every documented command is
    unchanged. The builder's batch-2 replay now goes through scopik's replay
    instead of carrying a second, less honest comparison. Drops the unused
    ml extra and the WASD viewer-flag workarounds (arrows are the scheme),
    and pins CI installs with uv sync --locked.
    [build_seeded_mujoco_model.py, check_env.py, drive_lqr_sim.py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]
2026-09-08 validate replay inputs and report timing adjustments in scopik
    Replay now refuses non-finite or missing commands and non-increasing
    timestamps instead of inventing zeros, rejects negative sensor indices,
    requires YAML booleans for gravity_compensated, and reports clipped
    intervals plus cumulative integration-time error in the gap output.
    Removes the parsed-but-unused scene.geom_filter.
2026-09-08 extract firmware control math and guard the torque path against NaN
    control_math.h holds the Arduino-independent command arbiter and
    balance-first torque allocation; host C++ tests compile it directly and
    replay the same command trace through the Python arbiter to hold parity.
    The active loop now latches a fault on any non-finite sensor state or
    torque before SetPosition. Entering preflight, convention check, or a
    trial resets the telemetry deadline so the idle 1 s schedule cannot
    starve telemetry_rate_hz and fail a healthy arming preflight. cppcheck
    now targets each sketch via check_src_filters (vendored lib defects
    suppressed), with a contract test tying check and build filters together.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
    [control_math.h, main.cpp, test_finn_lqr_contract.py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]
2026-09-08 fix the findings from the pre-merge review
    The blocker: rotation_vector_rate's dedup tolerance (50 ms) sat above the
    10 ms report interval, so a healthy 100 Hz quaternion stream collapsed to
    one arrival and reported the same signature as a dead sensor on the line
    an operator reads before release. Tolerance is now 1 ms, with healthy-rate
    and shared-arrival tests pinning both directions.
    Also from the review: Python allocate_wheel_torques now mirrors the C++
    fail-closed semantics instead of clamping NaN to max torque; the arbiter
    starts stale like the firmware, with the parity trace extended to cover
    the pre-first-command state; Batch 1 telemetry parsing tolerates a
    power-off-truncated final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
    [drive_lqr_sim.py, make_balance_demo.py]
